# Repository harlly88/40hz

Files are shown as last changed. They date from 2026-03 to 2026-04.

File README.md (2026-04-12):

# 40Hz Audio Modulation Project

## [中文版](readme_cn.md)

## Project Overview

This project implements a 40Hz audio modulation system based on the CH32V003F4P6 microcontroller. It features R-2R network DAC output, OLED display for status monitoring, and rotary encoder for volume control.

This system is based on scientific research showing that 40Hz auditory stimulation is effective in treating Alzheimer's disease in mouse and monkey models. My mother also suffers from Alzheimer's disease, which inspired me to develop this system.

- [Multisensory gamma stimulation promotes glymphatic clearance of amyloid](https://www.nature.com/articles/s41586-024-07132-6)
- [Long-term effects of forty-hertz auditory stimulation as a treatment of Alzheimer’s disease: Insights from an aged monkey model study](https://pmc.ncbi.nlm.nih.gov/articles/PMC12799102/)

## Hardware Architecture

### Core Components

1. **Main Controller**: CH32V003F4P6 (RISC-V Core, 24MHz)
2. **DAC Output**: 6-bit R-2R resistor network
3. **Display Module**: 128x64 OLED I2C display
4. **Input Device**: Rotary encoder with push button
5. **Power Supply**: USB-C 5V

### Pin Assignment

| Function | Pin | Description |
| --- | --- | --- |
| DAC BIT0 | PC0 | Least significant bit  |
| DAC BIT1 | PC3 | <br /> |
| DAC BIT2 | PC4 | <br /> |
| DAC BIT3 | PC5 | <br /> |
| DAC BIT4 | PC6 | <br /> |
| DAC BIT5 | PC7 | Most significant bit |
| I2C SCL | PC2 | OLED clock line |
| I2C SDA | PC1 | OLED data line |
| Encoder Phase A | PD5 | Rotary input A |
| Encoder Phase B | PD6 | Rotary input B |
| Encoder Button  | PD4 | Button input (pull-up) |

## Features

### Audio Modulation

- **Carrier Frequency**: 1kHz Sine Wave
- **Modulation Frequency**: 40Hz Sine Wave
- **Modulation Method**: Amplitude Modulation (AM)
- **Output Precision**: 6-bit R-2R DAC

### System Functions

1. **Volume Control**:
   - 0-63 level volume adjustment
   - Rotary encoder control
   - Auto-save volume to Flash memory
2. **Timer Function**:
   - Default 30-minute countdown
   - Auto-shutdown when time expires
   - Real-time remaining time display on OLED
3. **OLED Display**:
   - Project name
   - Current volume value
   - Remaining time
   - System status

## Software Implementation

### Core Algorithm

```c
// 1kHz sine wave table (64 points)
const u8 sine_table[SINE_TABLE_SIZE] = {
    32, 35, 38, 41, 44, 47, 50, 52,
    55, 57, 59, 61, 62, 63, 63, 63,
    63, 63, 63, 62, 61, 59, 57, 55,
    52, 50, 47, 44, 41, 38, 35, 32,
    29, 26, 23, 20, 17, 14, 11, 8,
    5,  3,  1,  0,  0,  0,  0,  0,
    0,  0,  0,  0,  1,  3,  5,  8,
    11, 14, 17, 20, 23, 26, 29, 32
};
```

### Modulation Principle

```c
// 40Hz AM modulation implementation
temp = (u16)sine_table[sine_index] * (am_value - 32) * volume / (64 * 64) + 32;
```

## Project Structure

```
.
├── PCB/                # Circuit board design files
│   ├── Schematic1/     # Schematic diagrams
│   ├── Gerber_PCB1_1_2026-04-08.zip  # Gerber files
│   └── PCB1_1.pcbdoc   # PCB design
├── Shell/              # 3D printed enclosure
│   ├── Back .stl
│   └── Front.stl
├── html/               # Web interface
│   └── index.html
└── software/           # Source code
    ├── 40HZ/           # Main project
    │   ├── Core/       # Core libraries
    │   ├── Debug/      # Debug module
    │   ├── Ld/         # Linker scripts
    │   ├── Peripheral/ # Peripheral drivers
    │   ├── Startup/    # Startup files
    │   └── User/       # User code
```

## Compilation and Programming

### Development Environment

- MounRiver Studio
- RISC-V GCC Toolchain
- WCH-Link Programmer

### Compilation Steps

1. Open MounRiver Studio
2. Import project: `software/40HZ/`
3. Compile the project
4. Generate `40HZ.hex` file

### Programming

1. Connect WCH-Link to development board
2. Select `40HZ.hex` file for programming
3. Execute programming

### PCB Manufacturing

The PCB files can be directly manufactured at [JLCPCB](https://www.jlc.com/).

<https://oshwhub.com/harlly/project_mxclzras>

### Programming Tool

Programming can be done using the [WCH-Link Programmer](https://www.wch.cn/downloads/WCH-LinkUtility_ZIP.html).

## User Guide

### Operation Instructions

1. **Power On**: Connect USB-C power
2. **Volume Adjustment**: Rotate encoder to adjust volume (0-63)
3. **Timer Function**: Default 30-minute countdown, auto-shutdown when time expires
4. **Volume Save**: Auto-save volume after 1 second of inactivity

### Display Interface

```
40Hz AM Wave
Volume: 32
Time: 30:00
```

## Hardware Manufacturing

### PCB Soldering

1. Solder CH32V003F4P6 microcontroller
2. Solder 6-bit R-2R resistor network
3. Solder OLED display module
4. Solder rotary encoder
5. Solder USB-C connector

### Enclosure

Shell/ 3D printed enclosure files

## Technical Details

### Clock Configuration

- System Clock: 24MHz
- TIM1 Timer: 64kHz interrupt
- Audio Output: 1kHz carrier wave
- Modulation Frequency: 40Hz

### Flash Memory

- Volume storage address: 0x08003C00
- Auto-save mechanism: Save after 1 second of volume change

## Appearance

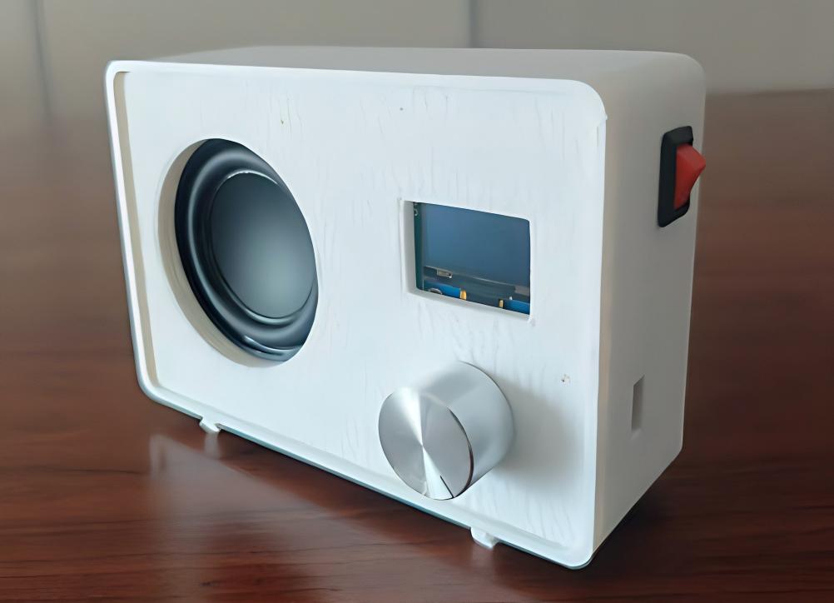
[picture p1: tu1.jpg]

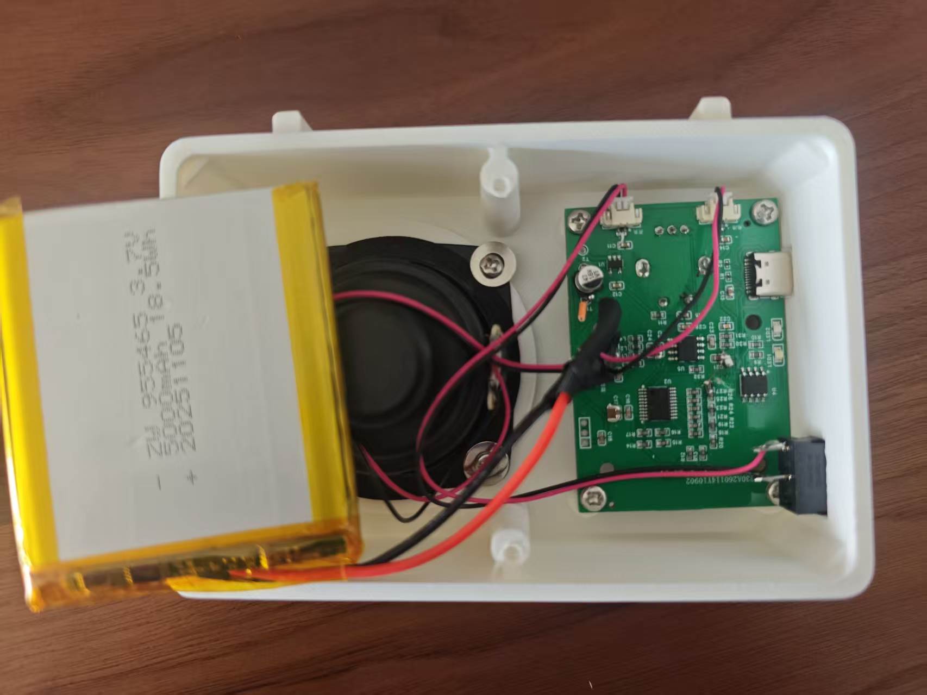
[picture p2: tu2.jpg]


## Troubleshooting

### Common Issues

1. **No Display**: Check OLED wiring connections
2. **No Audio Output**: Check R-2R network soldering
3. **Encoder Not Working**: Check pin connections
4. **Volume Not Saving**: Check Flash write code

## Version History

- V1.0.0 (2023/12/25): Initial release

## License

This project is based on WCH CH32V003 development board reference design, licensed under MIT License.

## References

- CH32V003 Datasheet
- SSD1315 OLED Driver Manual
- R-2R DAC Design Guide

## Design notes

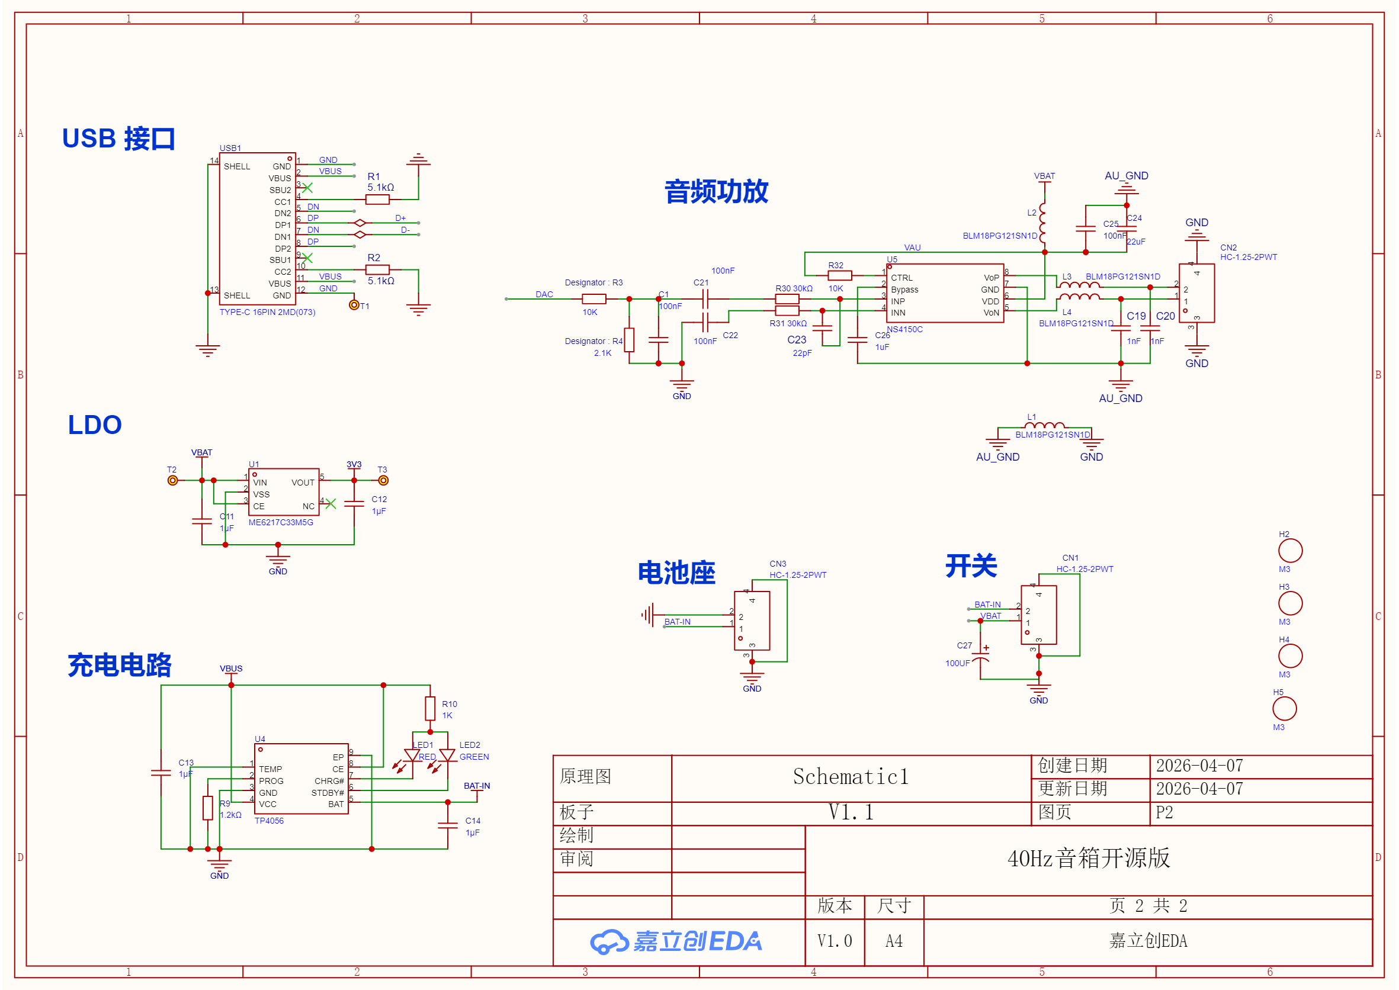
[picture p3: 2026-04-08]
PCB/SCH_Schematic1_2-P2_2026-04-08.png

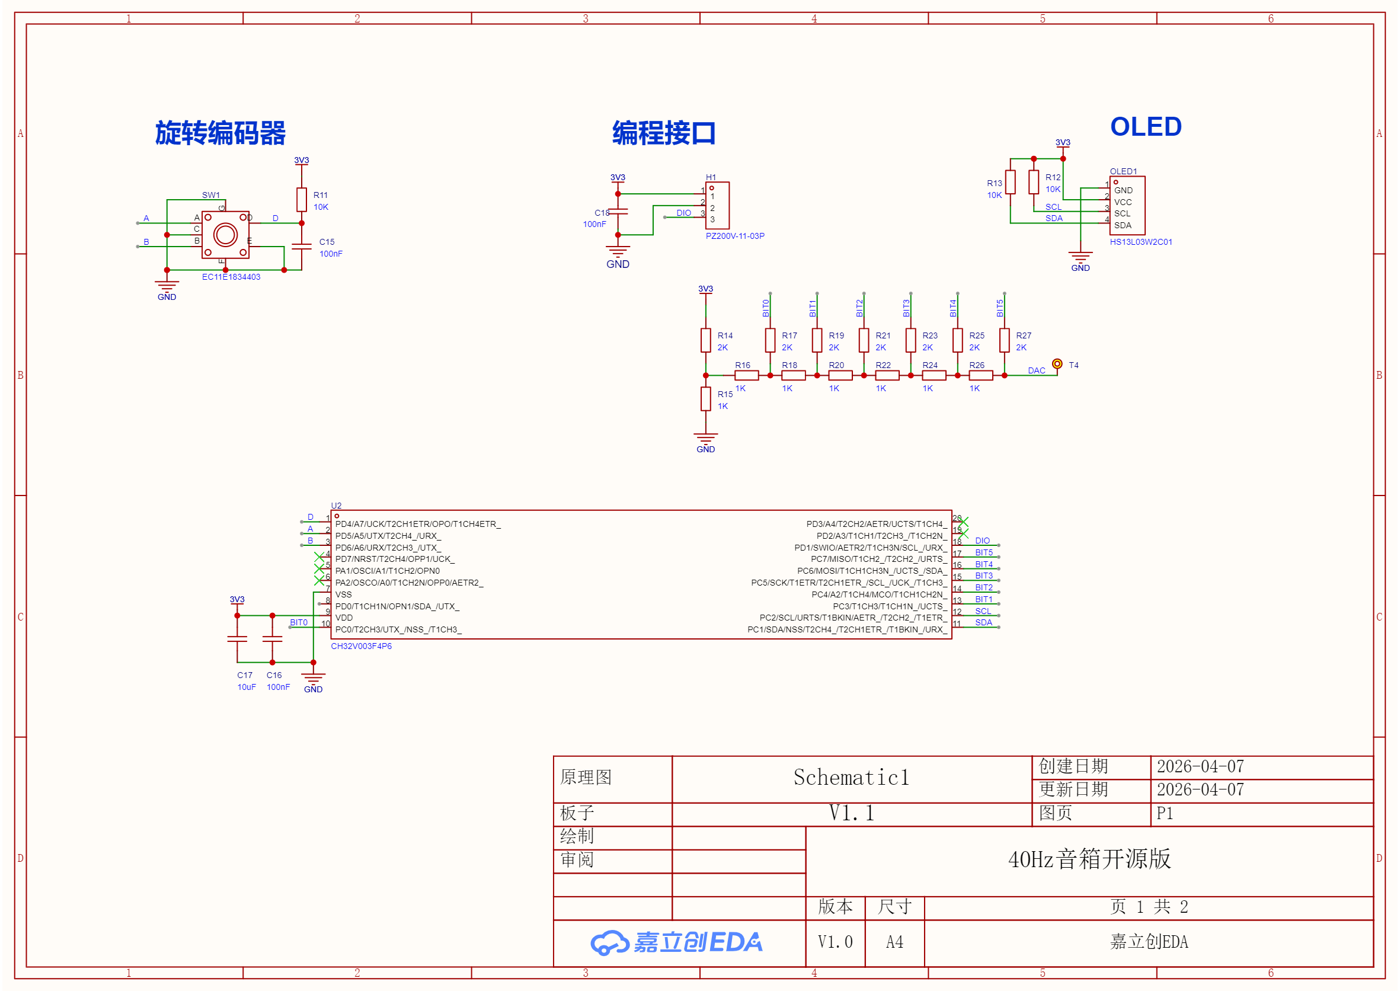
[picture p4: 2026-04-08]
PCB/SCH_Schematic1_1-P1_2026-04-08.png

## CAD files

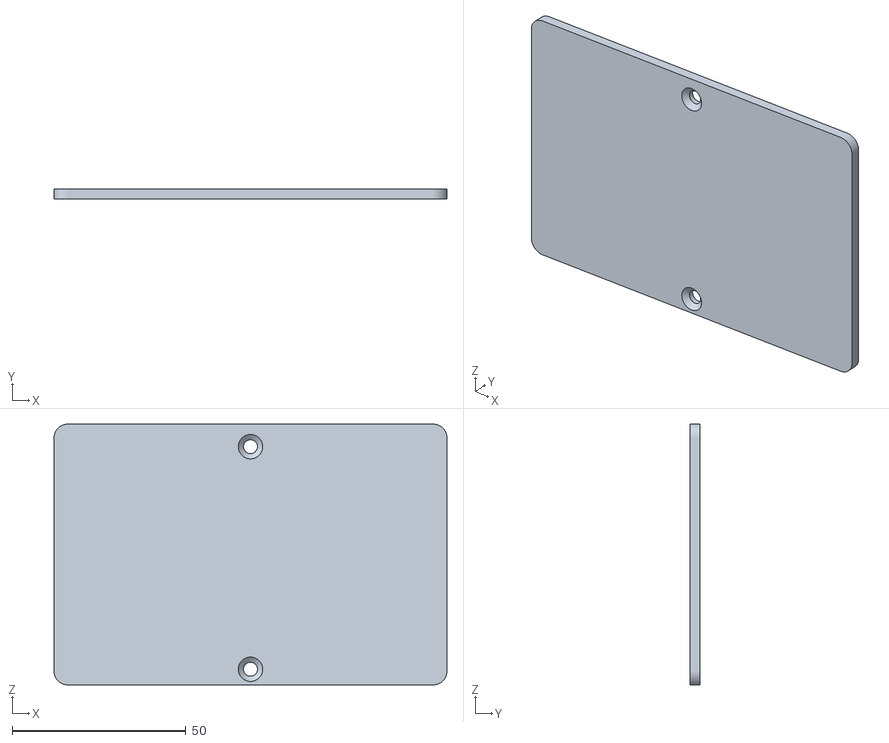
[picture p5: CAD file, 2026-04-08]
Shell/Back .stl
113.0 x 3.00 x 75.0

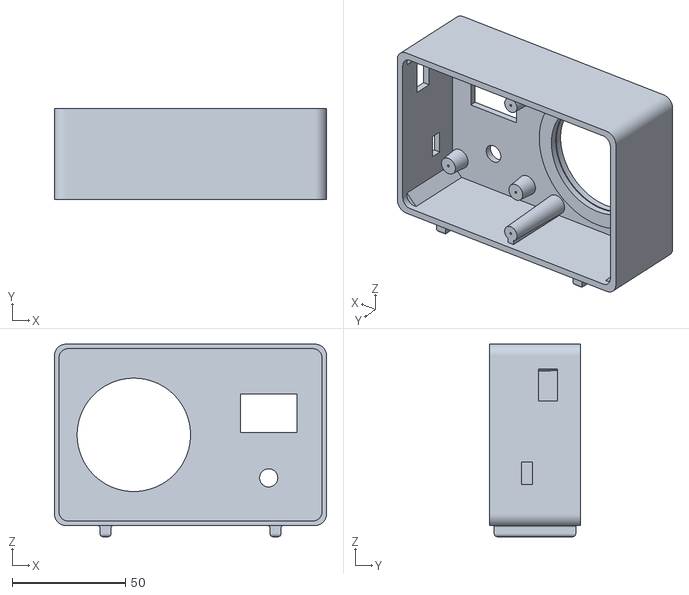
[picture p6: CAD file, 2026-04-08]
Shell/Front.stl
120.0 x 40.0 x 85.0

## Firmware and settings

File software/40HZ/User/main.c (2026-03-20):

/********************************** (C) COPYRIGHT *******************************
 * File Name          : main.c
 * Author             : WCH
 * Version            : V1.0.0
 * Date               : 2023/12/25
 * Description        : Main program body.
 *********************************************************************************
 * Copyright (c) 2021 Nanjing Qinheng Microelectronics Co., Ltd.
 * Attention: This software (modified or not) and binary are used for
 * microcontroller manufactured by Nanjing Qinheng Microelectronics.
 *******************************************************************************/

/*
 *@Note
 *40Hz AM 1kHz Sine Wave Output via R-2R DAC
 *R-2R DAC: 6-bit (BIT0-PC0, BIT1-PC3, BIT2-PC4, BIT3-PC5, BIT4-PC6, BIT5-PC7)
 *TIM1 generates interrupt at 12.8kHz to update DAC output
 *AM modulation: 1kHz sine wave modulated by 40Hz
 */

#include "debug.h"
#include "ch32v00x_i2c.h"
#include "ch32v00x_flash.h"
#include <stdlib.h>

#define SINE_TABLE_SIZE  64
#define OLED_I2C_ADDR    0x78  // OLED I2C地址

// Flash存储相关定义
#define FLASH_PAGE_SIZE    1024  // CH32V003 Flash页大小
#define VOLUME_STORE_ADDR  0x08003C00  // 音量存储地址（最后一页）

// ASCII字符集点阵数据声明
extern const u8 asc2_0808[][8];
extern const u8 asc2_0806[][6];
extern const u8 asc2_1608[][16];

// OLED驱动函数声明
void OLED_Init(void);
void OLED_Clear(void);
void OLED_ShowString(u8 x, u8 y, u8 *chr, u8 size);
void OLED_ShowChar(u8 x, u8 y, u8 chr, u8 size);
void OLED_ShowNum(u8 x, u8 y, u32 num, u8 len, u8 size);
u32 OLED_Pow(u8 m, u8 n);



// I2C驱动函数声明
void I2C_Init_OLED(void);
void I2C_SendByte(u8 addr, u8 data);
void OLED_WriteCmd(u8 cmd);
void OLED_WriteData(u8 data);

// Flash存储函数声明
u8 Flash_ReadVolume(void);
void Flash_SaveVolume(u8 volume);

const u8 sine_table[SINE_TABLE_SIZE] = {
    32, 35, 38, 41, 44, 47, 50, 52,
    55, 57, 59, 61, 62, 63, 63, 63,
    63, 63, 63, 62, 61, 59, 57, 55,
    52, 50, 47, 44, 41, 38, 35, 32,
    29, 26, 23, 20, 17, 14, 11, 8,
    5,  3,  1,  0,  0,  0,  0,  0,
    0,  0,  0,  0,  1,  3,  5,  8,
    11, 14, 17, 20, 23, 26, 29, 32
};

volatile u16 sine_index = 0;
volatile u8 am_index = 0;

// 定时功能相关变量
volatile u16 timer_count = 0;  // 定时器计数
volatile u8 countdown_minutes = 30;  // 倒计时分钟数
volatile u8 countdown_seconds = 0;  // 倒计时秒数
volatile u8 timer_running = 1;  // 定时器运行标志
volatile u8 timer_display = 0;  // 定时器显示标志

// 旋转编码器相关变量
volatile u8 encoder_state = 0;  // 编码器状态
volatile u16 encoder_count = 0;  // 编码器计数

// 设置参数
volatile int8_t volume;  // 音量（0-63）
volatile u8 last_volume_display = 0;  // 上一次显示的音量
volatile u8 last_saved_volume = 0;  // 上一次保存到Flash的音量

void DAC_GPIO_Init(void)
{
    GPIO_InitTypeDef GPIO_InitStructure = {0};

    RCC_APB2PeriphClockCmd(RCC_APB2Periph_GPIOC, ENABLE);

    GPIO_InitStructure.GPIO_Pin = GPIO_Pin_0 | GPIO_Pin_3 | GPIO_Pin_4 | GPIO_Pin_5 | GPIO_Pin_6 | GPIO_Pin_7;
    GPIO_InitStructure.GPIO_Mode = GPIO_Mode_Out_PP;
    GPIO_InitStructure.GPIO_Speed = GPIO_Speed_30MHz;
    GPIO_Init(GPIOC, &GPIO_InitStructure);

    GPIOC->BCR = GPIO_Pin_0 | GPIO_Pin_3 | GPIO_Pin_4 | GPIO_Pin_5 | GPIO_Pin_6 | GPIO_Pin_7;
}

void Encoder_GPIO_Init(void)
{
    GPIO_InitTypeDef GPIO_InitStructure = {0};

    RCC_APB2PeriphClockCmd(RCC_APB2Periph_GPIOD, ENABLE);

    // PD4 - 按键输入（上拉）
    GPIO_InitStructure.GPIO_Pin = GPIO_Pin_4;
    GPIO_InitStructure.GPIO_Mode = GPIO_Mode_IPU;
    GPIO_Init(GPIOD, &GPIO_InitStructure);

    // PD5 - A相输入（上拉）
    GPIO_InitStructure.GPIO_Pin = GPIO_Pin_5;
    GPIO_InitStructure.GPIO_Mode = GPIO_Mode_IPU;
    GPIO_Init(GPIOD, &GPIO_InitStructure);

    // PD6 - B相输入（上拉）
    GPIO_InitStructure.GPIO_Pin = GPIO_Pin_6;
    GPIO_InitStructure.GPIO_Mode = GPIO_Mode_IPU;
    GPIO_Init(GPIOD, &GPIO_InitStructure);
}

void DAC_Output(u8 value)
{
    u32 temp = value & 0x3F;

    if(temp & 0x01) GPIOC->BSHR = GPIO_Pin_0;
    else           GPIOC->BCR  = GPIO_Pin_0;

    if(temp & 0x02) GPIOC->BSHR = GPIO_Pin_3;
    else           GPIOC->BCR  = GPIO_Pin_3;

    if(temp & 0x04) GPIOC->BSHR = GPIO_Pin_4;
    else           GPIOC->BCR  = GPIO_Pin_4;

    if(temp & 0x08) GPIOC->BSHR = GPIO_Pin_5;
    else           GPIOC->BCR  = GPIO_Pin_5;

    if(temp & 0x10) GPIOC->BSHR = GPIO_Pin_6;
    else           GPIOC->BCR  = GPIO_Pin_6;

    if(temp & 0x20) GPIOC->BSHR = GPIO_Pin_7;
    else           GPIOC->BCR  = GPIO_Pin_7;
}

/*********************************************************************
 * @fn      Flash_ReadVolume
 * @brief   从Flash读取音量值
 * @return  音量值（0-63）
 ********************************************************************/
u8 Flash_ReadVolume(void)
{
    u32 *pFlash = (u32 *)VOLUME_STORE_ADDR;
    u8 volume = (u8)*pFlash;
    
    // 检查是否是有效的音量值
    if(volume >= 0 && volume <= 63)
    {
        return volume;
    }
    else
    {
        // 返回默认值
        return 32;
    }
}

/*********************************************************************
 * @fn      Flash_SaveVolume
 * @brief   将音量值保存到Flash
 * @param   volume - 要保存的音量值（0-63）
 * @return  none
 ********************************************************************/
void Flash_SaveVolume(u8 volume)
{
    FLASH_Status status;
    u32 PageAddr = VOLUME_STORE_ADDR & 0xFFFFFC00;  // 计算页地址
    
    // 限制音量范围
    if(volume > 63) volume = 63;
    if(volume < 0) volume = 0;
    
    // 解锁Flash
    FLASH_Unlock();
    
    // 擦除页
    status = FLASH_ErasePage(PageAddr);
    if(status != FLASH_COMPLETE)
    {
        // 擦除失败，上锁返回
        FLASH_Lock();
        return;
    }
    
    // 写入数据
    status = FLASH_ProgramWord(VOLUME_STORE_ADDR, volume);
    if(status != FLASH_COMPLETE)
    {
        // 写入失败，上锁返回
        FLASH_Lock();
        return;
    }
    
    // 上锁Flash
    FLASH_Lock();
}

void TIM1_Init(void)
{
    TIM_TimeBaseInitTypeDef TIM_TimeBaseInitStructure = {0};
    NVIC_InitTypeDef NVIC_InitStructure = {0};

    RCC_APB2PeriphClockCmd(RCC_APB2Periph_TIM1, ENABLE);

    // 系统时钟24MHz，预分频器0，周期374
    // 中断频率 = 24,000,000 / (1 × 375) = 64,000Hz
    // 载波频率 = 64,000Hz / 64点 = 1000Hz (精确1kHz)
    TIM_TimeBaseInitStructure.TIM_Period = 374;
    TIM_TimeBaseInitStructure.TIM_Prescaler = 0;
    TIM_TimeBaseInitStructure.TIM_ClockDivision = TIM_CKD_DIV1;
    TIM_TimeBaseInitStructure.TIM_CounterMode = TIM_CounterMode_Up;
    TIM_TimeBaseInitStructure.TIM_RepetitionCounter = 0;
    TIM_TimeBaseInit(TIM1, &TIM_TimeBaseInitStructure);

    TIM_ClearITPendingBit(TIM1, TIM_IT_Update);

    NVIC_InitStructure.NVIC_IRQChannel = TIM1_UP_IRQn;
    NVIC_InitStructure.NVIC_IRQChannelPreemptionPriority = 0;
    NVIC_InitStructure.NVIC_IRQChannelSubPriority = 0;
    NVIC_InitStructure.NVIC_IRQChannelCmd = ENABLE;
    NVIC_Init(&NVIC_InitStructure);

    TIM_ITConfig(TIM1, TIM_IT_Update, ENABLE);
    TIM_Cmd(TIM1, ENABLE);
}

/*********************************************************************
 * @fn      I2C_Init_OLED
 * @brief   初始化I2C总线，用于OLED显示
 * @return  none
 ********************************************************************/
void I2C_Init_OLED(void)
{
    GPIO_InitTypeDef GPIO_InitStructure = {0};
    I2C_InitTypeDef I2C_InitStructure = {0};

    RCC_APB2PeriphClockCmd(RCC_APB2Periph_GPIOC | RCC_APB2Periph_AFIO, ENABLE);
    RCC_APB1PeriphClockCmd(RCC_APB1Periph_I2C1, ENABLE);

    // 配置PC2为I2C_SCL
    GPIO_InitStructure.GPIO_Pin = GPIO_Pin_2;
    GPIO_InitStructure.GPIO_Mode = GPIO_Mode_AF_OD;  // 开漏输出
    GPIO_InitStructure.GPIO_Speed = GPIO_Speed_30MHz;
    GPIO_Init(GPIOC, &GPIO_InitStructure);

    // 配置PC1为I2C_SDA
    GPIO_InitStructure.GPIO_Pin = GPIO_Pin_1;
    GPIO_InitStructure.GPIO_Mode = GPIO_Mode_AF_OD;  // 开漏输出
    GPIO_InitStructure.GPIO_Speed = GPIO_Speed_30MHz;
    GPIO_Init(GPIOC, &GPIO_InitStructure);

    // 初始化I2C
    I2C_InitStructure.I2C_ClockSpeed = 400000;  // 400kHz
    I2C_InitStructure.I2C_Mode = I2C_Mode_I2C;
    I2C_InitStructure.I2C_DutyCycle = I2C_DutyCycle_2;
    I2C_InitStructure.I2C_OwnAddress1 = 0x00;
    I2C_InitStructure.I2C_Ack = I2C_Ack_Disable;
    I2C_InitStructure.I2C_AcknowledgedAddress = I2C_AcknowledgedAddress_7bit;
    I2C_Init(I2C1, &I2C_InitStructure);

    I2C_Cmd(I2C1, ENABLE);
}

/*********************************************************************
 * @fn      I2C_SendByte
 * @brief   I2C发送一个字节
 * @param   addr - 设备地址
 * @param   data - 要发送的数据
 * @return  none
 ********************************************************************/
void I2C_SendByte(u8 addr, u8 data)
{
    while(I2C_GetFlagStatus(I2C1, I2C_FLAG_BUSY) != RESET);

    I2C_GenerateSTART(I2C1, ENABLE);
    while(!I2C_CheckEvent(I2C1, I2C_EVENT_MASTER_MODE_SELECT));

    I2C_Send7bitAddress(I2C1, addr, I2C_Direction_Transmitter);
    while(!I2C_CheckEvent(I2C1, I2C_EVENT_MASTER_TRANSMITTER_MODE_SELECTED));

    I2C_SendData(I2C1, data);
    while(!I2C_CheckEvent(I2C1, I2C_EVENT_MASTER_BYTE_TRANSMITTED));

    I2C_GenerateSTOP(I2C1, ENABLE);
}

/*********************************************************************
 * @fn      OLED_WriteCmd
 * @brief   向OLED写入命令
 * @param   cmd - 命令字节
 * @return  none
 ********************************************************************/
void OLED_WriteCmd(u8 cmd)
{
    while(I2C_GetFlagStatus(I2C1, I2C_FLAG_BUSY) != RESET);

    I2C_GenerateSTART(I2C1, ENABLE);
    while(!I2C_CheckEvent(I2C1, I2C_EVENT_MASTER_MODE_SELECT));

    I2C_Send7bitAddress(I2C1, OLED_I2C_ADDR, I2C_Direction_Transmitter);
    while(!I2C_CheckEvent(I2C1, I2C_EVENT_MASTER_TRANSMITTER_MODE_SELECTED));

    I2C_SendData(I2C1, 0x00);  // 命令标志
    while(!I2C_CheckEvent(I2C1, I2C_EVENT_MASTER_BYTE_TRANSMITTED));

    I2C_SendData(I2C1, cmd);
    while(!I2C_CheckEvent(I2C1, I2C_EVENT_MASTER_BYTE_TRANSMITTED));

    I2C_GenerateSTOP(I2C1, ENABLE);
}

/*********************************************************************
 * @fn      OLED_WriteData
 * @brief   向OLED写入数据
 * @param   data - 数据字节
 * @return  none
 ********************************************************************/
void OLED_WriteData(u8 data)
{
    while(I2C_GetFlagStatus(I2C1, I2C_FLAG_BUSY) != RESET);

    I2C_GenerateSTART(I2C1, ENABLE);
    while(!I2C_CheckEvent(I2C1, I2C_EVENT_MASTER_MODE_SELECT));

    I2C_Send7bitAddress(I2C1, OLED_I2C_ADDR, I2C_Direction_Transmitter);
    while(!I2C_CheckEvent(I2C1, I2C_EVENT_MASTER_TRANSMITTER_MODE_SELECTED));

    I2C_SendData(I2C1, 0x40);  // 数据标志
    while(!I2C_CheckEvent(I2C1, I2C_EVENT_MASTER_BYTE_TRANSMITTED));

    I2C_SendData(I2C1, data);
    while(!I2C_CheckEvent(I2C1, I2C_EVENT_MASTER_BYTE_TRANSMITTED));

    I2C_GenerateSTOP(I2C1, ENABLE);
}


// 读取旋转编码器状态
void Encoder_Read(void)
{
    static u8 last_a = 1, last_b = 1;
    u8 current_a, current_b;

    // 读取A相和B相状态
    current_a = GPIO_ReadInputDataBit(GPIOD, GPIO_Pin_5);
    current_b = GPIO_ReadInputDataBit(GPIOD, GPIO_Pin_6);

    // 检测旋转方向（改进的AB相检测算法）
    if(current_a != last_a)
    {
        if(current_b != current_a)
        {
            encoder_count++;
        }
        else
        {
            encoder_count--;
        }
    }
    else if(current_b != last_b)
    {
        if(current_a == current_b)
        {
            encoder_count++;
        }
        else
        {
            encoder_count--;
        }
    }

    last_a = current_a;
    last_b = current_b;
}

/*********************************************************************
 * @fn      OLED_Init
 * @brief   初始化SSD1315 OLED显示屏（根据官方数据手册）
 * @return  none
 ********************************************************************/
void OLED_Init(void)
{
    Delay_Ms(100);  // 电源稳定延迟

    OLED_WriteCmd(0xAE);  // 关闭显示
    OLED_WriteCmd(0xD5);  // 设置时钟分频因子,震荡频率
    OLED_WriteCmd(0x80);  // [3:0],分频因子;[7:4],震荡频率
    OLED_WriteCmd(0xA8);  // 设置驱动路数
    OLED_WriteCmd(0x3F);  // 1/64 duty (128*64分辨率)
    OLED_WriteCmd(0xD3);  // 设置显示偏移
    OLED_WriteCmd(0x00);  // 无偏移
    OLED_WriteCmd(0x40);  // 设置显示开始行 [5:0],行数.
    OLED_WriteCmd(0x8D);  // 电荷泵设置
    OLED_WriteCmd(0x14);  // 开启电荷泵
    OLED_WriteCmd(0x20);  // 设置内存地址模式
    OLED_WriteCmd(0x02);  // 页地址模式
    OLED_WriteCmd(0xA1);  // 段重定义设置,0->127 (左右翻转)
    OLED_WriteCmd(0xC8);  // COM扫描方向;COM[N-1]->COM0 (上下翻转)
    OLED_WriteCmd(0xDA);  // 设置COM硬件引脚配置
    OLED_WriteCmd(0x12);  // [5:4]配置
    OLED_WriteCmd(0x81);  // 对比度设置
    OLED_WriteCmd(0xCF);  // 128
    OLED_WriteCmd(0xD9);  // 设置预充电周期
    OLED_WriteCmd(0xF1);  // [3:0],PHASE 1;[7:4],PHASE 2;
    OLED_WriteCmd(0xDB);  // 设置VCOMH取消选择级别
    OLED_WriteCmd(0x30);  // [6:4] 000,0.65*vcc;001,0.77*vcc;011,0.83*vcc
    OLED_WriteCmd(0xA4);  // 全局显示开启;bit0:1,开启;0,关闭
    OLED_WriteCmd(0xA6);  // 设置显示方式;bit0:1,反相显示;0,正常显示
    OLED_WriteCmd(0xAF);  // 开启显示

    OLED_Clear();  // 清屏
}


/*********************************************************************
 * @fn      OLED_Clear
 * @brief   清屏函数
 * @return  none
 ********************************************************************/
void OLED_Clear(void)
{
    u8 i, n;
    for(i = 0; i < 8; i++)
    {
        OLED_WriteCmd(0xB0 + i);  // 设置页地址
        OLED_WriteCmd(0x00);      // 设置显示位置-列低地址
        OLED_WriteCmd(0x10);      // 设置显示位置-列高地址
        for(n = 0; n < 128; n++)
        {
            OLED_WriteData(0x00);  // 写入空数据
        }
    }
}

/*********************************************************************
 * @fn      OLED_ShowChar
 * @brief   显示一个字符（适配SSD1315 128*64）
 * @param   x - 起始列地址
 * @param   y - 起始页地址
 * @param   chr - 要显示的字符
 * @param   size - 字符大小
 * @return  none
 ********************************************************************/
void OLED_ShowChar(u8 x, u8 y, u8 chr, u8 size)
{
    u8 c = 0, i = 0;
    c = chr - ' ';  // 得到偏移后的值
    if(x > 128 - size) { x = 0; y += 1; }

    if(size == 16)
    {
        // 设置页地址
        OLED_WriteCmd(0xB0 + y);
        // 设置列地址高4位
        OLED_WriteCmd(0x10 | (x >> 4));
        // 设置列地址低4位
        OLED_WriteCmd(x & 0x0F);
        
        // 显示上半部分
        for(i = 0; i < 8; i++)
        {
            OLED_WriteData(asc2_1608[c][i]);
        }
        
        // 设置下一页
        OLED_WriteCmd(0xB0 + y + 1);
        // 设置列地址高4位
        OLED_WriteCmd(0x10 | (x >> 4));
        // 设置列地址低4位
        OLED_WriteCmd(x & 0x0F);

    }
    else if(size == 8)
    {
        // 8x8字体
        OLED_WriteCmd(0xB0 + y);
        OLED_WriteCmd(0x10 | (x >> 4));
        OLED_WriteCmd(x & 0x0F);
        for(i = 0; i < 8; i++)
        {
            OLED_WriteData(asc2_0808[c][i]);
        }
    }
    else
    {
        // 8x6字体（暂时不使用）
        OLED_WriteCmd(0xB0 + y);
        OLED_WriteCmd(0x10 | (x >> 4));
        OLED_WriteCmd(x & 0x0F);
        for(i = 0; i < 6; i++)
        {
            OLED_WriteData(asc2_0806[c][i]);
        }
    }
}

/*********************************************************************
 * @fn      OLED_ShowString
 * @brief   显示字符串
 * @param   x - 起始列地址
 * @param   y - 起始页地址
 * @param   chr - 要显示的字符串
 * @param   size - 字符大小
 * @return  none
 ********************************************************************/
void OLED_ShowString(u8 x, u8 y, u8 *chr, u8 size)
{
    while(*chr != '\0')
    {
        OLED_ShowChar(x, y, *chr, size);
        x += size;
        if(x > 128)
        {
            x = 0;
            y += 2;
        }
        chr++;
    }
}

/*********************************************************************
 * @fn      OLED_ShowNum
 * @brief   显示数字
 * @param   x - 起始列地址
 * @param   y - 起始页地址
 * @param   num - 要显示的数字
 * @param   len - 数字长度
 * @param   size - 字符大小
 * @return  none
 ********************************************************************/
void OLED_ShowNum(u8 x, u8 y, u32 num, u8 len, u8 size)
{
    u8 t, temp;
    u8 enshow = 0;

    for(t = 0; t < len; t++)
    {
        temp = (num / OLED_Pow(10, len - t - 1)) % 10;
        if(enshow == 0 && t < len - 1)
        {
            if(temp == 0)
            {
                OLED_ShowChar(x + (size * t), y, ' ', size);
                continue;
            }
            else
            {
                enshow = 1;
            }
        }
        OLED_ShowChar(x + (size * t), y, temp + '0', size);
    }
}

/*********************************************************************
 * @fn      OLED_Pow
 * @brief   求幂函数
 * @param   m - 底数
 * @param   n - 指数
 * @return  m^n
 ********************************************************************/
u32 OLED_Pow(u8 m, u8 n)
{
    u32 result = 1;
    while(n--)
    {
        result *= m;
    }
    return result;
}
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
int main(void)
{
    NVIC_PriorityGroupConfig(NVIC_PriorityGroup_1);
    SystemCoreClockUpdate();
    Delay_Init();

    // 从Flash读取音量
    volume = Flash_ReadVolume();
    last_saved_volume = volume;

    // 初始化DAC GPIO
    DAC_GPIO_Init();

    // 初始化旋转编码器GPIO
    Encoder_GPIO_Init();

    // 初始化I2C和OLED
    I2C_Init_OLED();
    OLED_Init();

    // 显示信息（使用8x8字体）
    OLED_ShowString(0, 0, "40Hz AM Wave", 8);
    //OLED_ShowString(0, 2, "Freq: 1kHz", 8);
    OLED_ShowString(0, 2, "Volume: ", 8);
    OLED_ShowNum(64, 2, volume, 2, 8);  // 显示初始音量
    OLED_ShowString(0, 6, "Time: ", 8);

    // 初始化TIM1
    TIM1_Init();

    while(1)
    {
        // 读取旋转编码器
        Encoder_Read();

        // 处理编码器旋转控制音量
        static u16 last_encoder_count = 0;
        if(encoder_count != last_encoder_count)
        {
            u16 diff = encoder_count - last_encoder_count;
            last_encoder_count = encoder_count;

            // 直接调整音量，正数增加，负数减少
            volume += diff ;

            // 限制音量范围0-63
            volume = volume > 63 ? 63 : volume < 0 ? 0 : volume;
        }

        // 更新音量显示
        if(volume != last_volume_display)
        {
            last_volume_display = volume;
            OLED_ShowNum(64, 2, volume, 2, 8);
        }

        // 自动保存音量到Flash（音量变化超过5或停止操作1秒）
        static u16 save_timer = 0;
        if(volume != last_saved_volume)
        {
            save_timer++;
            if(save_timer >= 100)  // 100*10ms=1秒
            {
                Flash_SaveVolume((u8)volume);
                last_saved_volume = volume;
                save_timer = 0;
            }
        }
        else
        {
            save_timer = 0;
        }

        // 延时
        Delay_Ms(10);
        // 更新倒计时显示
        if(timer_display)
        {
            timer_display = 0;  // 重置显示标志 
            OLED_ShowNum(64, 6, countdown_minutes, 2, 8);
            OLED_ShowChar(80, 6, ':', 8);
            OLED_ShowNum(88, 6, countdown_seconds, 2, 8);
            if(countdown_seconds < 10)
            {
                OLED_ShowChar(88, 6, '0', 8);
            }
        }
    }
}

void TIM1_UP_IRQHandler(void) __attribute__((interrupt("WCH-Interrupt-fast")));
void TIM1_UP_IRQHandler(void)
{
    u8 am_value;
    u16 temp;
 

    if(timer_running)
    {
        // 恢复AM调制
        am_value = sine_table[am_index];
        // 调整调制深度，避免输出饱和
        // 加入音量控制
        temp = (u16)sine_table[sine_index] * (am_value - 32) * volume / (64 * 64) + 32 ;

        if(temp > 63) temp = 63;
        if(temp < 0) temp = 0;

        DAC_Output((u8)temp);

        sine_index++;
        if(sine_index >= SINE_TABLE_SIZE)
        {
            sine_index = 0;
        }

        // 调整AM调制索引更新速度，实现40Hz调制
        // 1kHz / 40Hz = 25，每25次载波更新一次调制
        static u8 am_step = 0;
        am_step++;
        if(am_step >= 25)
        {
            am_step = 0;
            am_index++;
            if(am_index >= SINE_TABLE_SIZE)
            {
                am_index = 0;
            }
        }

        // 定时器计数（1秒中断）
        timer_count++;
        if(timer_count >= 64000)
        {
            timer_count = 0;
            countdown_seconds--;
            timer_display = 1;  // 标记需要更新显示
            if(countdown_seconds == 255)  // 下溢
            {
                countdown_seconds = 59;
                countdown_minutes--;
                if(countdown_minutes == 255)  // 下溢，定时结束
                {
                    timer_running = 0;
                    TIM_Cmd(TIM1, DISABLE);  // 关闭TIM1定时器
                    DAC_Output(0);  // 关闭DAC输出
                    OLED_ShowString(64, 6, " 00:00", 8);
                    timer_display = 0;  // 重置显示标志
                    return;
                }
            }
           

        }
    }

    TIM_ClearITPendingBit(TIM1, TIM_IT_Update);
}

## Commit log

2026-03-18 1kHz正弦波输出正常
    [CH32V003F4P6-R0-1v1.PcbDoc, CH32V003F4P6-R0-1v1.SchDoc]
2026-03-18 40HZ调制1khz 调制波形输出正常
2026-03-19 可以显示，但间隔有问题
2026-03-19 显示正常，在调定时
2026-03-19 倒计时正常
2026-03-19 按键可以使用，有抖动
2026-03-19 重新修复了DAC输出
2026-03-19 字符设定设为常量
2026-03-19 旋钮改为调音量
2026-03-20 增加了调节音量
2026-03-20 音量保存到flash
2026-04-08 重新修改了目录名称
    [Back .stl, CH32V003F4P6-R0-1v1.PcbDoc, CH32V003F4P6-R0-1v1.SchDoc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]
2026-04-08 增加readme文件
    [CH32V003F4P6-R0-1v1.PcbDoc, CH32V003F4P6-R0-1v1.SchDoc, P1.schdoc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]
2026-04-08 增加英文readme
2026-04-11 更改readme文件
2026-04-12 增加图片
2026-04-12 增加了嘉立创链接
